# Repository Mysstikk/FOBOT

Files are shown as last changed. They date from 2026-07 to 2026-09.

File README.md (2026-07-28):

# FOBOT — Feeding Collaborative Robot

FOBOT es un prototipo de robot colaborativo de seis grados de libertad diseñado para asistir durante la alimentación de personas con movilidad reducida o diversidad funcional.

El sistema combina actuadores Dynamixel, ROS 2, MoveIt 2 y visión artificial para ejecutar una secuencia de recogida de comida y aproximar una cuchara a la boca del usuario mediante control visual.

Este repositorio contiene el código fuente desarrollado para el Trabajo de Fin de Grado:

> *Design and implementation of a collaborative robot for feeding with control through artificial vision*

Autor: Unai Mollá Caballero  
Tutor: Jaime Masiá Vañó  
Universitat Politècnica de València — Campus d'Alcoi  
Curso: 2025–2026

## Características principales

- Control de seis actuadores Dynamixel.
- Integración del hardware mediante `ros2_control`.
- Ejecución de trayectorias articulares previamente configuradas.
- Grabación de posiciones mediante guiado manual.
- Coordinación del comportamiento mediante una máquina de estados finitos.
- Detección facial mediante MediaPipe.
- Reconocimiento de la apertura de la boca y el cierre de los ojos.
- Estimación tridimensional de la posición de la boca.
- Aproximación mediante MoveIt Servo.
- Supervisión de singularidades y colisiones.
- Detección de posibles contactos mediante el esfuerzo de los motores.
- Interfaz física mediante pulsadores e indicadores LED.

## Arquitectura del repositorio

```text
FOBOT/
├── robot_pkg/                 # Control principal, FSM y movimientos
├── fobot_moveit_config/       # Configuración de MoveIt 2
├── fobot_vision/              # Detección facial y control visual
├── singularity_probe/         # Análisis del jacobiano
├── DynamixelSDK               # SDK de los motores Dynamixel
├── dynamixel_interfaces/      # Mensajes y servicios de Dynamixel
├── dynamixel_hardware_interface/
│                              # Integración con ros2_control
└── README.md
```

La estructura puede variar dependiendo de la versión publicada.

## Requisitos

El sistema se ha desarrollado utilizando:

- Ubuntu 22.04.
- ROS 2 Humble.
- Python 3.
- C++.
- MoveIt 2.
- `ros2_control`.
- Dynamixel SDK.
- OpenCV.
- MediaPipe.
- Cámara USB.
- Raspberry Pi 4.

También se necesitan los paquetes de ROS 2 correspondientes a MoveIt Servo, TF2, `usb_cam` y el controlador de trayectorias articulares.

## Instalación

Crear un espacio de trabajo de ROS 2:

```bash
mkdir -p ~/fobot_ws/src
cd ~/fobot_ws/src
```

Clonar el repositorio:

```bash
git clone <URL_DEL_REPOSITORIO>
```

Instalar las dependencias:

```bash
cd ~/fobot_ws
rosdep install --from-paths src --ignore-src -r -y
```

Compilar:

```bash
colcon build --symlink-install
source install/setup.bash
```

La instrucción `source install/setup.bash` debe ejecutarse en cada nueva terminal desde la que se utilice el robot.

## Configuración previa

Antes de iniciar el sistema se debe comprobar:

1. Que cada motor Dynamixel tenga un identificador diferente.
2. Que el puerto serie y la velocidad de comunicación sean correctos.
3. Que la cámara esté conectada y calibrada.
4. Que el plato y el robot estén situados en las posiciones utilizadas durante la configuración.
5. Que la cuchara esté limpia y correctamente fijada.
6. Que no haya obstáculos dentro del espacio de trabajo.

Los parámetros principales se encuentran en los archivos YAML de los paquetes correspondientes.

## Ejecución

Para iniciar el sistema completo:

```bash
ros2 launch robot_pkg FOBOT.launch.py
```

El fichero maestro inicia los controladores, la descripción del robot, la máquina de estados, el sistema de visión y MoveIt Servo.

Después del arranque se debe realizar el movimiento de *homing* antes de comenzar la secuencia de alimentación.

## Grabación de trayectorias

El movimiento automático utiliza una secuencia de posiciones articulares almacenada en un fichero CSV.

El programa de grabación permite:

1. Desactivar el par de los motores.
2. Mover manualmente el brazo.
3. Registrar las posiciones deseadas.
4. Volver a activar el par.
5. Probar la trayectoria antes de utilizarla con comida.

Las primeras pruebas deben realizarse sin situar al usuario dentro del alcance inmediato del robot.

## Funcionamiento general

La secuencia de alimentación es la siguiente:

1. El robot realiza el movimiento de *homing*.
2. El usuario abre la boca para iniciar el ciclo.
3. El robot ejecuta la trayectoria de recogida.
4. La cuchara se desplaza hasta una posición próxima al rostro.
5. El usuario vuelve a abrir la boca para confirmar la entrega.
6. El sistema de visión estima la posición de la boca.
7. MoveIt Servo realiza la aproximación final.
8. El robot regresa para recoger una nueva porción.
9. El usuario puede finalizar el proceso cerrando ambos ojos.

## Limitaciones

El prototipo presenta actualmente las siguientes limitaciones:

- No detecta automáticamente la comida presente en el plato.
- La recogida utiliza trayectorias previamente grabadas.
- El plato debe permanecer en una posición aproximadamente fija.
- La profundidad se estima mediante una cámara RGB monocular.
- El comportamiento puede verse afectado por la iluminación y las oclusiones.
- No se ha realizado una validación clínica ni una certificación de seguridad.
- El sistema debe utilizarse en un entorno controlado y con supervisión.

## Seguridad

Este software pertenece a un prototipo académico y no constituye un producto médico o asistencial certificado.

Antes de utilizarlo:

- Mantener despejado el espacio de trabajo.
- No introducir las manos mientras los motores estén activos.
- Comprobar la temperatura y consistencia de la comida.
- Verificar la fijación de la cuchara.
- No rearmar el sistema sin identificar la causa de la parada.
- Utilizar el interruptor de alimentación si el robot presenta un comportamiento inesperado.

El uso del código y del prototipo se realiza bajo la responsabilidad de la persona que lo instala y opera.

Unai Mollá Caballero

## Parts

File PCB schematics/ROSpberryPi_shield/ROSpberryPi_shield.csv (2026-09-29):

Reference | Value | Datasheet | Footprint | Qty
C1 | 100uf |  | Capacitor_SMD:CP_Elec_8x10.5 | 1
C2 | 100nf |  | Capacitor_Tantalum_SMD:CP_EIA-1608-10_AVX-L | 1
C3 | 100nf |  | Capacitor_Tantalum_SMD:CP_EIA-1608-10_AVX-L | 1
C4 | 100nf |  | Capacitor_Tantalum_SMD:CP_EIA-1608-10_AVX-L | 1
C5 | 100nf |  | Capacitor_Tantalum_SMD:CP_EIA-1608-10_AVX-L | 1
C6 | 100nf |  | Capacitor_Tantalum_SMD:CP_EIA-1608-10_AVX-L | 1
C7 | 100nf |  | Capacitor_Tantalum_SMD:CP_EIA-1608-10_AVX-L | 1
C8 | 100nf |  | Capacitor_Tantalum_SMD:CP_EIA-1608-10_AVX-L | 1
C9 | 100nf |  | Capacitor_Tantalum_SMD:CP_EIA-1608-10_AVX-L | 1
C10 | 100nf |  | Capacitor_Tantalum_SMD:CP_EIA-1608-10_AVX-L | 1
C11 | 100nf |  | Capacitor_Tantalum_SMD:CP_EIA-1608-10_AVX-L | 1
C12 | 100nf |  | Capacitor_Tantalum_SMD:CP_EIA-1608-10_AVX-L | 1
D1 | RED |  | LED_SMD:LED_0201_0603Metric | 1
D2 | SS34 | http://www.vishay.com/docs/88526/1n5820.pdf | Diode_THT:D_DO-201AD_P15.24mm_Horizontal | 1
D3 | GREEN |  | LED_SMD:LED_0603_1608Metric | 1
D4 | PESD5V0L1BA | https://datasheet.datasheetarchive.com/originals/distributors/Datasheets-26/DSA-502684.pdf | My_Lib:SOD2512X110N | 1
IC3 | NC7WZ241K8X | https://www.onsemi.com/pub/Collateral/NC7WZ241-D.PDF | My_Lib:SOP50P310X90-8N | 1
J1 | Conn_01x03_Pin |  | Connector_Molex:Molex_KK-254_AE-6410-03A_1x03_P2.54mm_Vertical | 1
J8 | Conn_01x03_Pin |  | Connector_Molex:Molex_KK-254_AE-6410-03A_1x03_P2.54mm_Vertical | 1
J9 | Conn_01x03_Pin |  | Connector_Molex:Molex_KK-254_AE-6410-03A_1x03_P2.54mm_Vertical | 1
J11 | Conn_01x03_Pin |  | Connector_Molex:Molex_KK-254_AE-6410-03A_1x03_P2.54mm_Vertical | 1
J12 | Conn_01x03_Pin |  | Connector_Molex:Molex_KK-254_AE-6410-03A_1x03_P2.54mm_Vertical | 1
J13 | Conn_01x03_Pin |  | Connector_Molex:Molex_KK-254_AE-6410-03A_1x03_P2.54mm_Vertical | 1
J14 | Conn_01x03_Pin |  | Connector_Molex:Molex_KK-254_AE-6410-03A_1x03_P2.54mm_Vertical | 1
J15 | Conn_01x03_Pin |  | Connector_Molex:Molex_KK-254_AE-6410-03A_1x03_P2.54mm_Vertical | 1
J16 | Conn_01x04_Pin |  | Connector_Molex:Molex_KK-254_AE-6410-04A_1x04_P2.54mm_Vertical | 1
R1 | 390 |  | Resistor_SMD:R_0201_0603Metric | 1
R2 | 220 |  | Resistor_SMD:R_0201_0603Metric | 1
R3 | 150 |  | Resistor_SMD:R_0201_0603Metric | 1
R4 | 150 |  | Resistor_SMD:R_0201_0603Metric | 1
R5 | 100 |  | Resistor_SMD:R_0201_0603Metric | 1
R6 | 100 |  | Resistor_SMD:R_0201_0603Metric | 1
R7 | 10k |  | Resistor_SMD:R_0201_0603Metric | 1
R8 | 2.2k |  | Resistor_SMD:R_0201_0603Metric | 1
R9 | 2.2k |  | Resistor_SMD:R_0201_0603Metric | 1
U2 | BNO085 |  | My_Lib:IC_BNO085 | 1
U3 | TXB0104D | http://www.ti.com/lit/ds/symlink/txb0104.pdf | Package_SO:SOIC-14_3.9x8.7mm_P1.27mm | 1
U4 | MCP3008 | http://ww1.microchip.com/downloads/en/DeviceDoc/21295d.pdf | Package_DIP:DIP-16_W7.62mm | 1

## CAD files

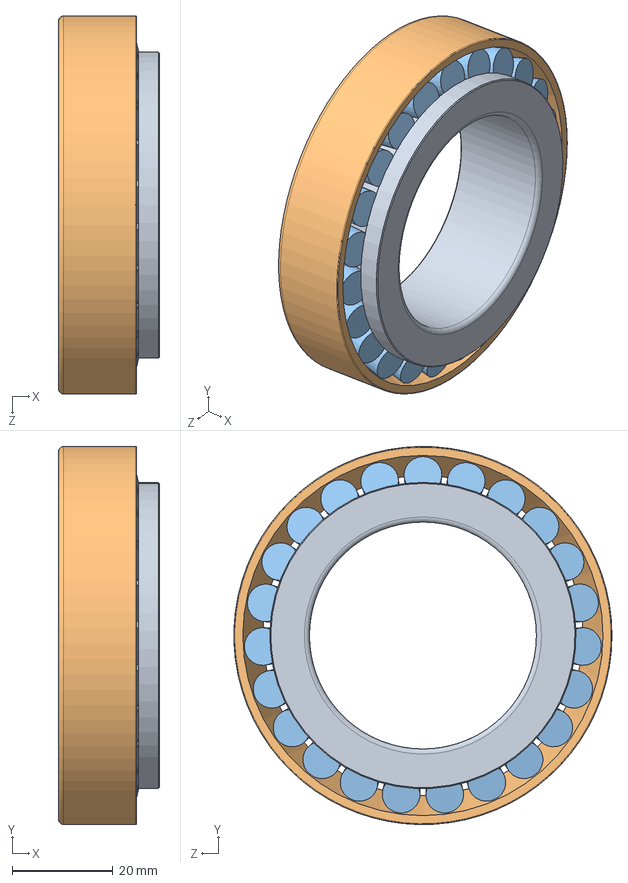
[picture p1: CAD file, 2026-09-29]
model/skf_bearing_32009_x_2.SLDASM
20.0 x 75.0 x 75.0 mm
skf_bearing_32009_x_2_01
skf_bearing_32009_x_2_02
skf_bearing_32009_x_2_03

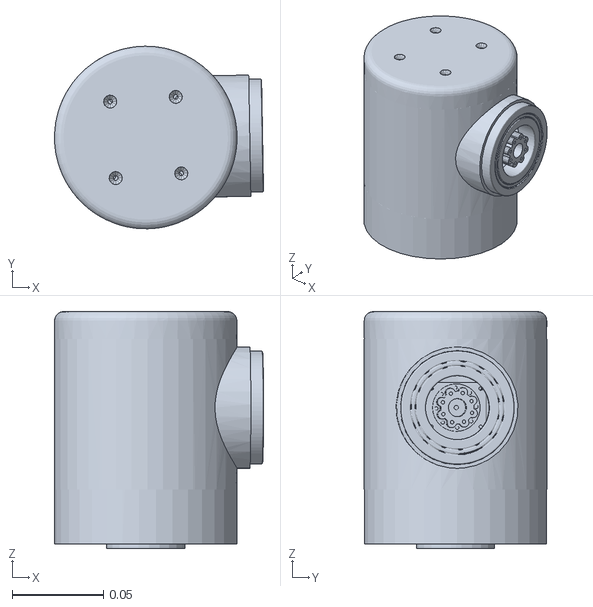
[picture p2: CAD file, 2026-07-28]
robot_pkg/urdf/meshes/link_hombro.STL
0.115 x 0.1 x 0.13

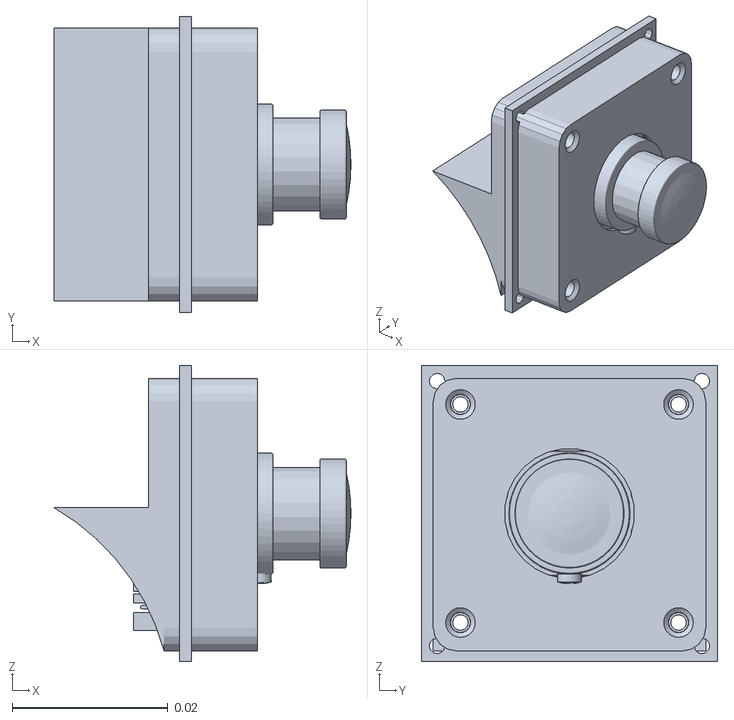
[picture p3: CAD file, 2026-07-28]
robot_pkg/urdf/meshes/link_camara.STL
0.0381 x 0.038 x 0.038

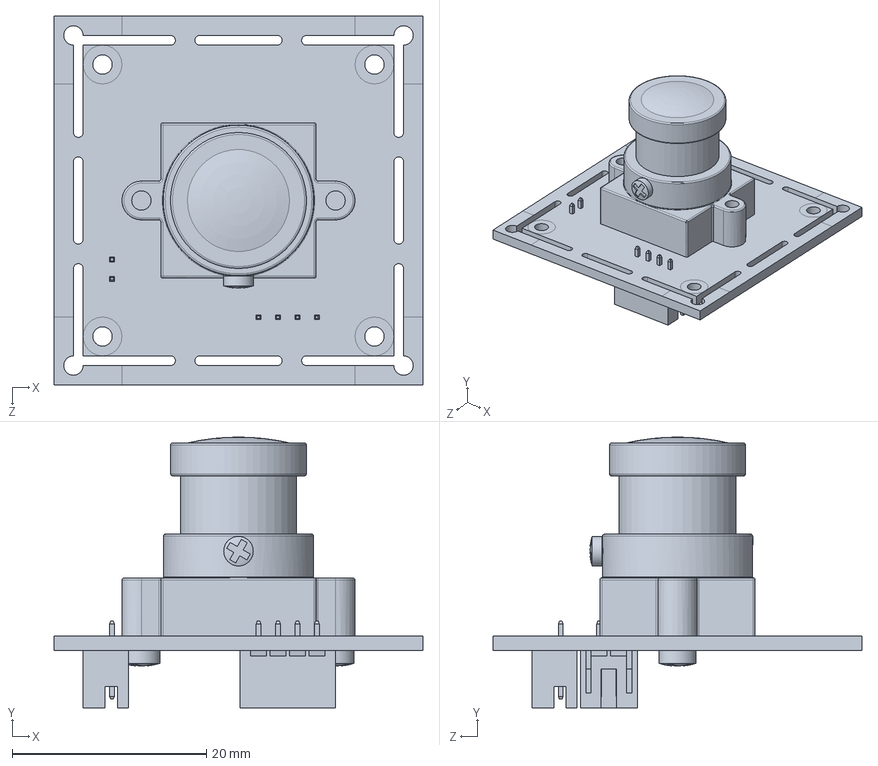
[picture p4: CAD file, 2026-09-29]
model/USB Cam model ELP-USBFHD01M-L21.SLDPRT
38.0 x 27.9 x 38.0 mm

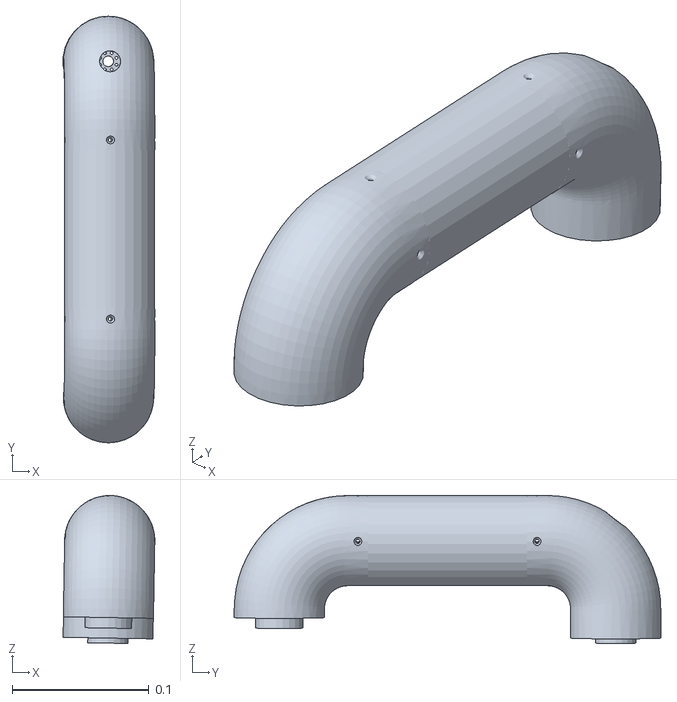
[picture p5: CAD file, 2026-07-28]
robot_pkg/urdf/meshes/link_hombro_codo.STL
0.0671 x 0.312 x 0.108

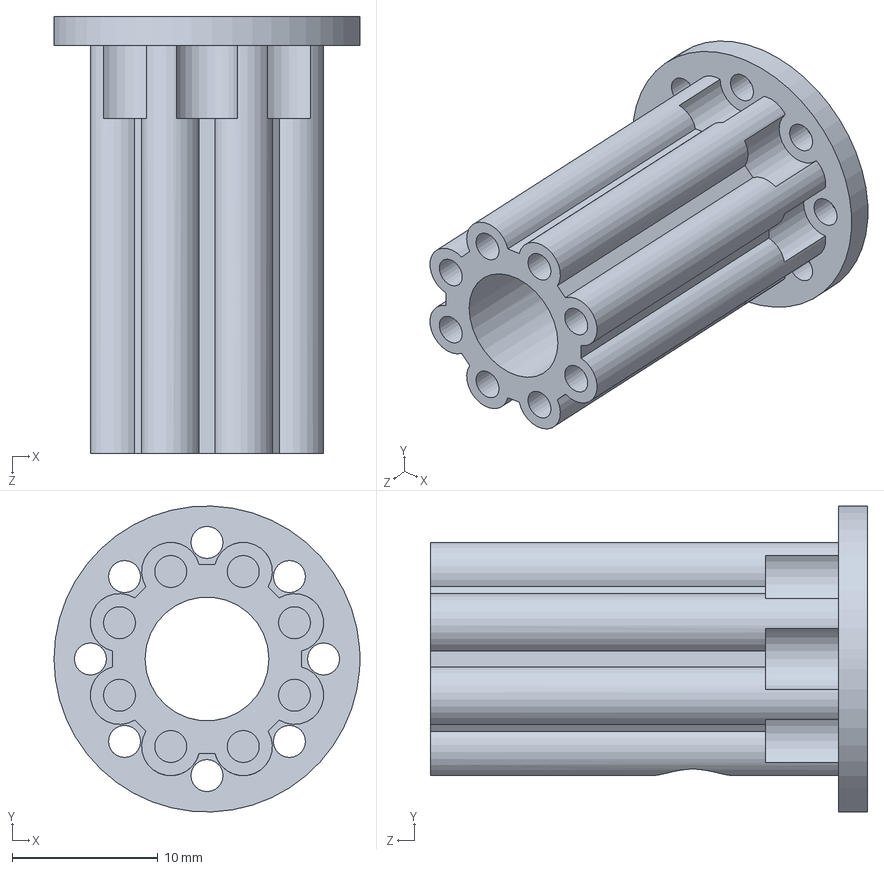
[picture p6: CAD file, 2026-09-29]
model/Soporte_Eslabon_3.SLDPRT
21.0 x 21.0 x 30.0 mm

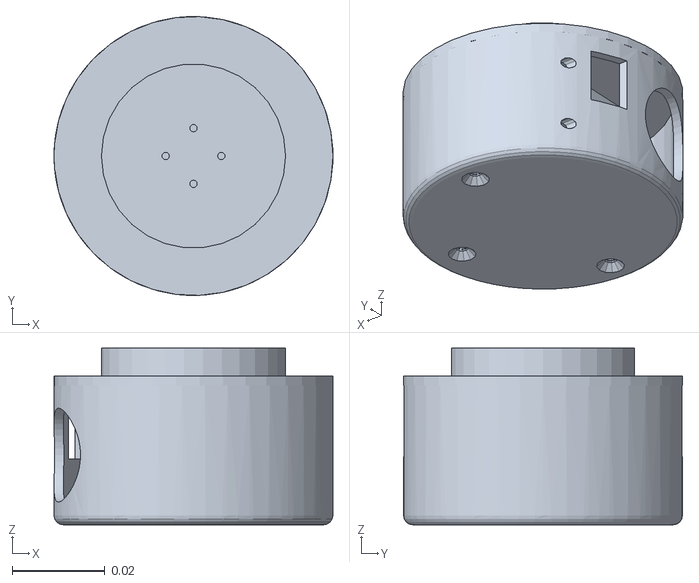
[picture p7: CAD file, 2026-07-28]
robot_pkg/urdf/meshes/link_muneca.STL
0.06 x 0.06 x 0.038

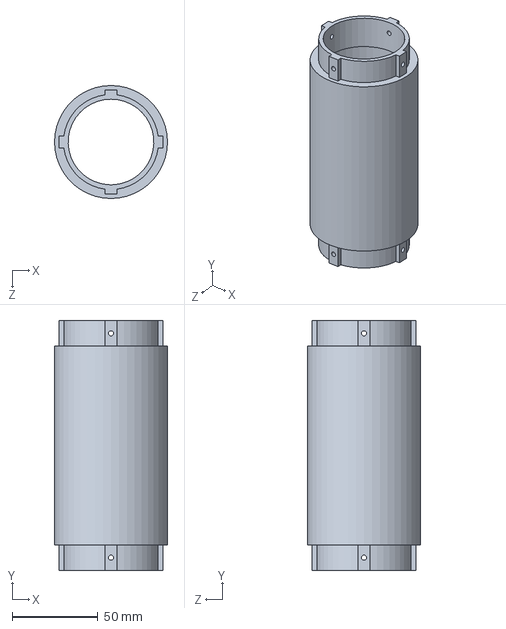
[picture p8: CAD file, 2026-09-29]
model/Eslabon_3.SLDPRT
66.0 x 146.0 x 66.0 mm

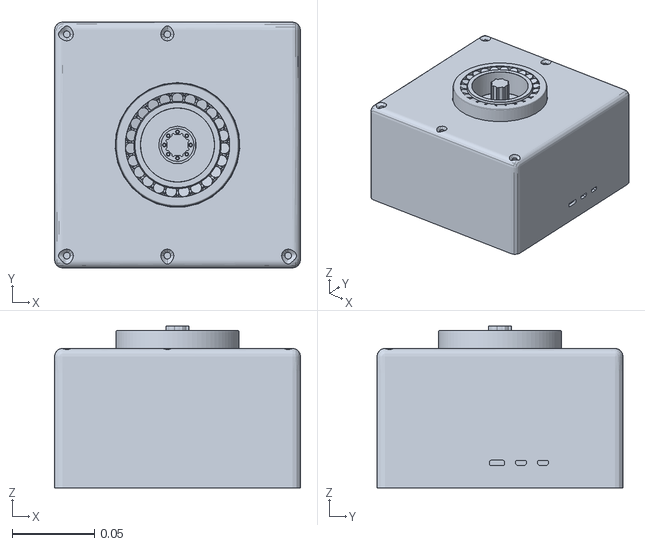
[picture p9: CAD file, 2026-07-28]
robot_pkg/urdf/meshes/base_link.STL
0.15 x 0.15 x 0.0985

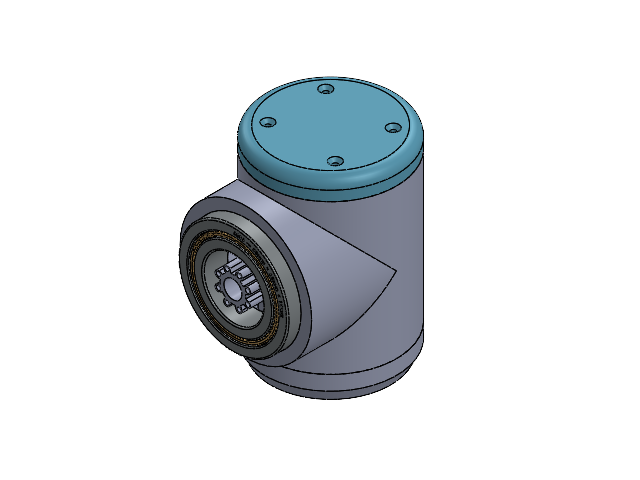
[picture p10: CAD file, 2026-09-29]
model/Eslabon_Codo.SLDASM
Eslabon_4
Cubierta_Eslabon_3
Tapa_Eslabon_3
DUMMY_DC12.stp
WBH_M2_5X12.stp x 8
DC12_A01_SPACER_RING_1.stp x 8
DC12_A01_CVR_CABLE_5.stp
p BEARING, SINGLE-ROW RADIAL, OPEN, METRIC 6000 SERIES — 6006 — 30mm × 55mm × 13mm
Pieza1^Eslabon_Codo

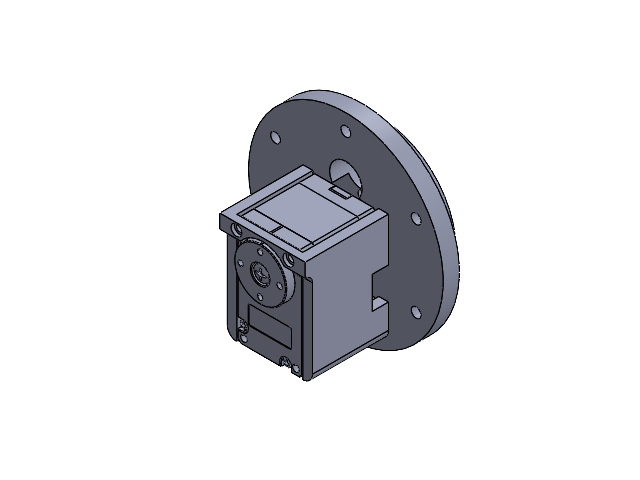
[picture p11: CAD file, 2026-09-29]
model/Eslabon_Muneca_Herramienta.SLDASM
Eslabon_5
DC15_A01_CASE_M_DUMMY.stp
DC15_A01_CASE_F_DUMMY.stp
DC15_A01_CASE_B_DUMMY.stp
DC15_A01_HORN_DUMMY.stp
DC15_A01_LED_CAP2_DUMMY.stp
PHS_1_7X20_5_DC10.stp x 4
BTS2_M2_6X8.stp
B3B-EH.stp x 2
Pieza1^Eslabon_Muneca_Herramienta

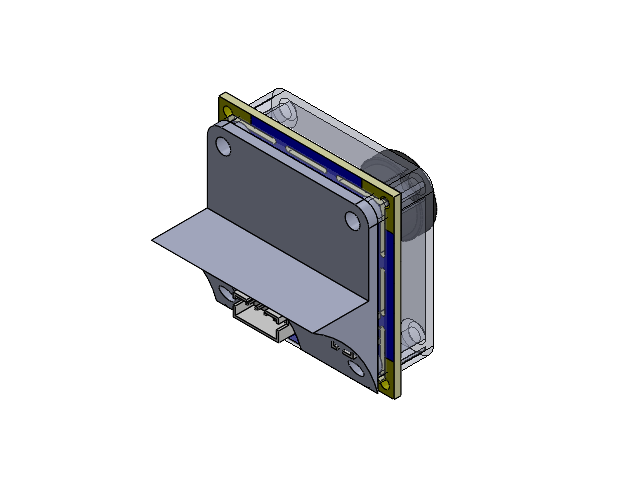
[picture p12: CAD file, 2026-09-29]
model/Ensamb_Camara.SLDASM
Soporte_Camara
Tapa_Camara
USB Cam model ELP-USBFHD01M-L21

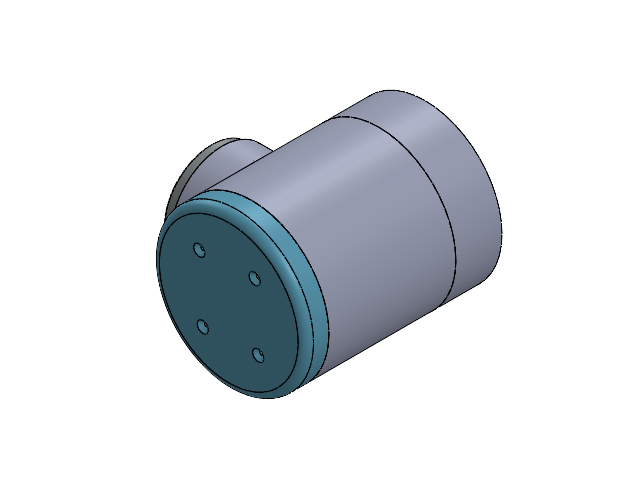
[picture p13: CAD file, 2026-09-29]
model/Eslabon_Hombro.SLDASM
Eslabon_1
XM540.step
Cubierta_Eslabon_1
p BEARING, SINGLE-ROW RADIAL, OPEN, METRIC 6000 SERIES — 6007 — 35mm × 62mm × 14mm
Soporte_Eslabon_2
Tapa_Eslabon_1

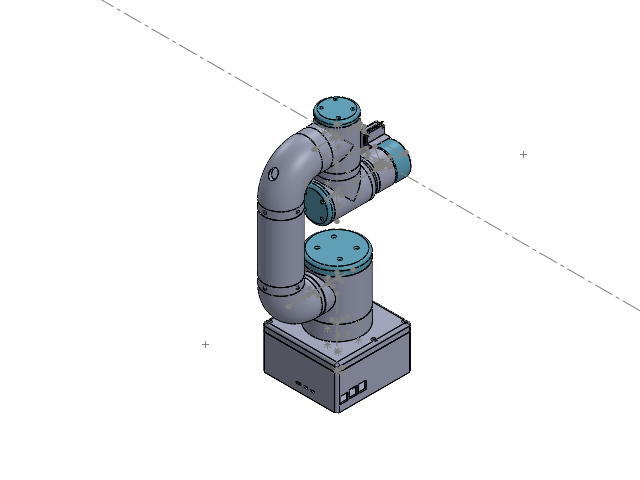
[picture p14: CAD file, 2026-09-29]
model/FOBOT.SLDASM
BaseRobot
Tapa_Base_Robot
DUMMY_DC12.stp x 3
WBH_M2_5X12.stp x 24
DC12_A01_SPACER_RING_1.stp x 24
DC12_A01_CVR_CABLE_5.stp x 3
Soporte_Eslabon
skf_bearing_32009_x_2_01
skf_bearing_32009_x_2_02
skf_bearing_32009_x_2_03
Eslabon_1
XM540.step
Cubierta_Eslabon_1
p BEARING, SINGLE-ROW RADIAL, OPEN, METRIC 6000 SERIES — 6007 — 35mm × 62mm × 14mm
Soporte_Eslabon_2
Tapa_Eslabon_1
Eslabon_2
Cubierta_Eslabon_2
p BEARING, SINGLE-ROW RADIAL, OPEN, METRIC 6000 SERIES — 6006 — 30mm × 55mm × 13mm x 2
Tapa_Eslabon_2
Soporte_Eslabon_3
Eslabon_3_2
Eslabon_3
Eslabon_3_2_sup
Eslabon_4
Cubierta_Eslabon_3
Tapa_Eslabon_3
Pieza1^Eslabon_Codo
Eslabon_5
Cubierta_Eslabon_5
61808-2rs1_01
61808-2rs1_02
61808-2rs1_03
61808-2rs1_04
61808-2rs1_05
DC15_A01_CASE_M_DUMMY.stp x 2
DC15_A01_CASE_F_DUMMY.stp x 2
DC15_A01_CASE_B_DUMMY.stp x 2
DC15_A01_HORN_DUMMY.stp x 2
DC15_A01_LED_CAP2_DUMMY.stp x 2
PHS_1_7X20_5_DC10.stp x 8
BTS2_M2_6X8.stp x 2
B3B-EH.stp x 4
Pieza1^Eslabon_Muneca_Herramienta
Eslabon_6
Soporte_Herramienta
Herramienta_1
Tapa_Herramienta
Soporte_Camara
Tapa_Camara
USB Cam model ELP-USBFHD01M-L21

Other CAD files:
model/Base_Robot.SLDASM
model/Eslabon_Hombro_Codo.SLDASM
model/Eslabon_Herramienta.SLDASM
robot_pkg/urdf/meshes/link_tcp.STL
model/61808-2rs1.SLDASM
model/61808-2rs1_01.SLDPRT
model/61808-2rs1_02.SLDPRT
model/61808-2rs1_03.SLDPRT
model/61808-2rs1_04.SLDPRT
model/61808-2rs1_05.SLDPRT
model/BaseRobot.SLDPRT
model/Cubierta_Eslabon_1.SLDPRT
model/Cubierta_Eslabon_2.SLDPRT
model/Cubierta_Eslabon_3.SLDPRT
model/Cubierta_Eslabon_5.SLDPRT
model/Eslabon_1.SLDPRT
model/Eslabon_2.SLDPRT
model/Eslabon_3_2.SLDPRT
model/Eslabon_3_2_sup.SLDPRT
model/Eslabon_4.SLDPRT
model/Eslabon_5.SLDPRT
model/Eslabon_6.SLDPRT
model/Herramienta_1.SLDPRT
model/Pieza1^Eslabon_Codo.SLDPRT
model/Soporte_Camara.SLDPRT
model/Soporte_Eslabon.SLDPRT
model/Soporte_Eslabon_2.SLDPRT
model/Soporte_Herramienta.SLDPRT
model/Tapa_Base_Robot.SLDPRT
model/Tapa_Camara.SLDPRT
model/Tapa_Eslabon_1.SLDPRT
model/Tapa_Eslabon_2.SLDPRT
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

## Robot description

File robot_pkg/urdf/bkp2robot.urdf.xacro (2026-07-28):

<?xml version="1.0" encoding="utf-8"?>
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
<robot name="FOBOT" xmlns:xacro="http://www.ros.org/wiki/xacro">
  <link name="world_link" />

  <joint name="world_joint" type="fixed">
    <parent link="world_link" />
    <child link="base_link" />
    <origin xyz="0 0 0" rpy="0 0 0" />
  </joint>
  <link name="base_link">
    <inertial>
      <origin xyz="-0.000324527792386832 0.000535590007123509 0.0536555243566054" rpy="0 0 0" />
      <mass value="0.640667020480894" />
      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
    </inertial>
    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
  </link>
  <link name="link_hombro">
    <inertial>
      <origin xyz="0.0177586720760899 0.000311723505450981 0.0594351103623852" rpy="0 0 0" />
      <mass value="0.654879795952153" />
      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
    </inertial>
    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
  </link>
  <joint name="joint_hombro" type="revolute">
    <origin xyz="0 0 0.0831" rpy="0 0 0" />
    <parent link="base_link" />
    <child link="link_hombro" />
    <axis xyz="0 0 1" />
    <limit lower="-1.57" upper="1.57" effort="10" velocity="3.14" />
  </joint>
  <link name="link_hombro_codo">
    <inertial>
      <origin xyz="0.00174671434810424 0.127639245502884 0.0995470053851245" rpy="0 0 0" />
      <mass value="0.36538432537355" />
      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
    </inertial>
    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
  </link>
  <joint name="joint_hombro_codo" type="revolute">
    <origin xyz="0 0 0.07715" rpy="1.5708 0 1.5708" />
    <parent link="link_hombro" />
    <child link="link_hombro_codo" />
    <axis xyz="0 0 1" />
    <limit lower="-1.57" upper="1.57" effort="10" velocity="3.14" />
  </joint>
  <link name="link_codo">
    <inertial>
      <origin xyz="-0.00516428980556016 -0.000391330935633924 0.0223035602244459" rpy="0 0 0" />
      <mass value="0.314093246133126" />
      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
    </inertial>
    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
  </link>
  <joint name="joint_codo" type="revolute">
    <origin xyz="0 0.246 0" rpy="0 0 1.5708" />
    <parent link="link_hombro_codo" />
    <child link="link_codo" />
    <axis xyz="0 0 -1" />
    <limit lower="-1.57" upper="1.57" effort="10" velocity="3.14" />
  </joint>
  <link name="link_codo_muneca">
    <inertial>
      <origin xyz="-1.39307723388693E-07 0.0135191619848798 0.0172025714731864" rpy="0 0 0" />
      <mass value="0.392047475790556" />
      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
    </inertial>
    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
  </link>
  <joint name="joint_codo_muneca" type="revolute">
    <origin xyz="-0.09705 0 0" rpy="-1.5708 0 -1.5708" />
    <parent link="link_codo" />
    <child link="link_codo_muneca" />
    <axis xyz="0 0 -1" />
    <limit lower="-1.57" upper="1.57" effort="10" velocity="3.14" />
  </joint>
  <link name="link_muneca">
    <inertial>
      <origin xyz="0.0011814 -0.00012981 -0.014057" rpy="0 0 0" />
      <mass value="0.051202" />
      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
    </inertial>
    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
  </link>
  <joint name="joint_muneca" type="revolute">
    <origin xyz="0 0.086566 0" rpy="1.5708 0 0" />
    <parent link="link_codo_muneca" />
    <child link="link_muneca" />
    <axis xyz="0 0 -1" />
    <limit lower="-1.57" upper="1.57" effort="10" velocity="3.14" />
  </joint>
  <link name="link_herramienta">
    <inertial>
      <origin xyz="-0.0066648 -0.00010158 -0.053829" rpy="0 0 0" />
      <mass value="0.010917" />
      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
    </inertial>
    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
  </link>
  <joint name="joint_herramienta" type="revolute">
    <origin xyz="0 -0.0075 -0.018384" rpy="1.5708 0 1.5708" />
    <parent link="link_muneca" />
    <child link="link_herramienta" />
    <axis xyz="0 0 -1" />
    <limit lower="-1.57" upper="1.57" effort="10" velocity="3.14" />
  </joint>
  <link name="link_tcp">
    
  </link>
  <joint name="joint_tcp_fixed" type="fixed">
    <origin xyz="0 0 -0.10829" rpy="0 1.5708 0" />
    <parent link="link_herramienta" />
    <child link="link_tcp" />
    <axis xyz="0 0 0" />
  </joint>
  <link name="link_camara">
    <inertial>
      <origin xyz="-0.019021 -9.3975E-05 -0.00037502" rpy="0 0 0" />
      <mass value="0.012812" />
      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
    </inertial>
    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
  </link>
  <joint name="joint_camara_fixed" type="fixed">
    <origin xyz="-0.052668 0.025492 -0.018384" rpy="1.5708 0 -3.1416" />
    <parent link="link_muneca" />
    <child link="link_camara" />
    <axis xyz="0 0 0" />
  </joint>
  
  <ros2_control name="DynamixelSystem" type="system">
    <hardware>
      <plugin>dynamixel_hardware_interface/DynamixelHardware</plugin>
      
      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
      <param name="port_name">/dev/ttyUSB0</param>
      
      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
      <param name="baud_rate">1000000</param>
      <param name="protocol_version">2.0</param>
      <param name="use_dummy">false</param> 
      <param name="error_timeout_sec">1.0</param>
      <param name="number_of_joints">6</param> 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
      <param name="number_of_transmissions">6</param> 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
      <param name="disable_torque_at_init">true</param> 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
      <param name="error_timeout_sec">0.2</param>
      <param name="dynamixel_model_folder">/param/dxl_model</param> 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
      <param name="transmission_to_joint_matrix">
      1,0,0,0,0,0,
      0,1,0,0,0,0,
      0,0,1,0,0,0,
      0,0,0,1,0,0,
      0,0,0,0,1,0,
      0,0,0,0,0,1
      </param>
      <param name="joint_to_transmission_matrix">
      1,0,0,0,0,0,
      0,1,0,0,0,0,
      0,0,1,0,0,0,
      0,0,0,1,0,0,
      0,0,0,0,1,0,
      0,0,0,0,0,1
      </param>
      
      <param name="ros_update_freq">200</param>
      <param name="dynamixel_state_pub_msg_name">dynamixel_hardware_interface/dxl_state</param>
      <param name="get_dynamixel_data_srv_name">dynamixel_hardware_interface/get_dxl_data</param>
      <param name="set_dynamixel_data_srv_name">dynamixel_hardware_interface/set_dxl_data</param>
      <param name="reboot_dxl_srv_name">dynamixel_hardware_interface/reboot_dxl</param>
      <param name="set_dxl_torque_srv_name">dynamixel_hardware_interface/set_dxl_torque</param>
    </hardware>

    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
    <joint name="joint_hombro">
      <command_interface name="position"/>
      <state_interface name="position"/>
      <state_interface name="velocity"/>
      <state_interface name="effort"/>
    </joint>
    
    <joint name="joint_hombro_codo">
      <command_interface name="position"/>
      <state_interface name="position"/>
      <state_interface name="velocity"/>
      <state_interface name="effort"/>
    </joint>
    
    <joint name="joint_codo">
      <command_interface name="position"/>
      <state_interface name="position"/>
      <state_interface name="velocity"/>
      <state_interface name="effort"/>
    </joint>
    
    <joint name="joint_codo_muneca">
      <command_interface name="position"/>
      <state_interface name="position"/>
      <state_interface name="velocity"/>
      <state_interface name="effort"/>
    </joint>
    
    <joint name="joint_muneca">
      <command_interface name="position"/>
      <state_interface name="position"/>
      <state_interface name="velocity"/>
      <state_interface name="effort"/>
    </joint>
    
    <joint name="joint_herramienta">
      <command_interface name="position"/>
      <state_interface name="position"/>
      <state_interface name="velocity"/>
      <state_interface name="effort"/>
    </joint>
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

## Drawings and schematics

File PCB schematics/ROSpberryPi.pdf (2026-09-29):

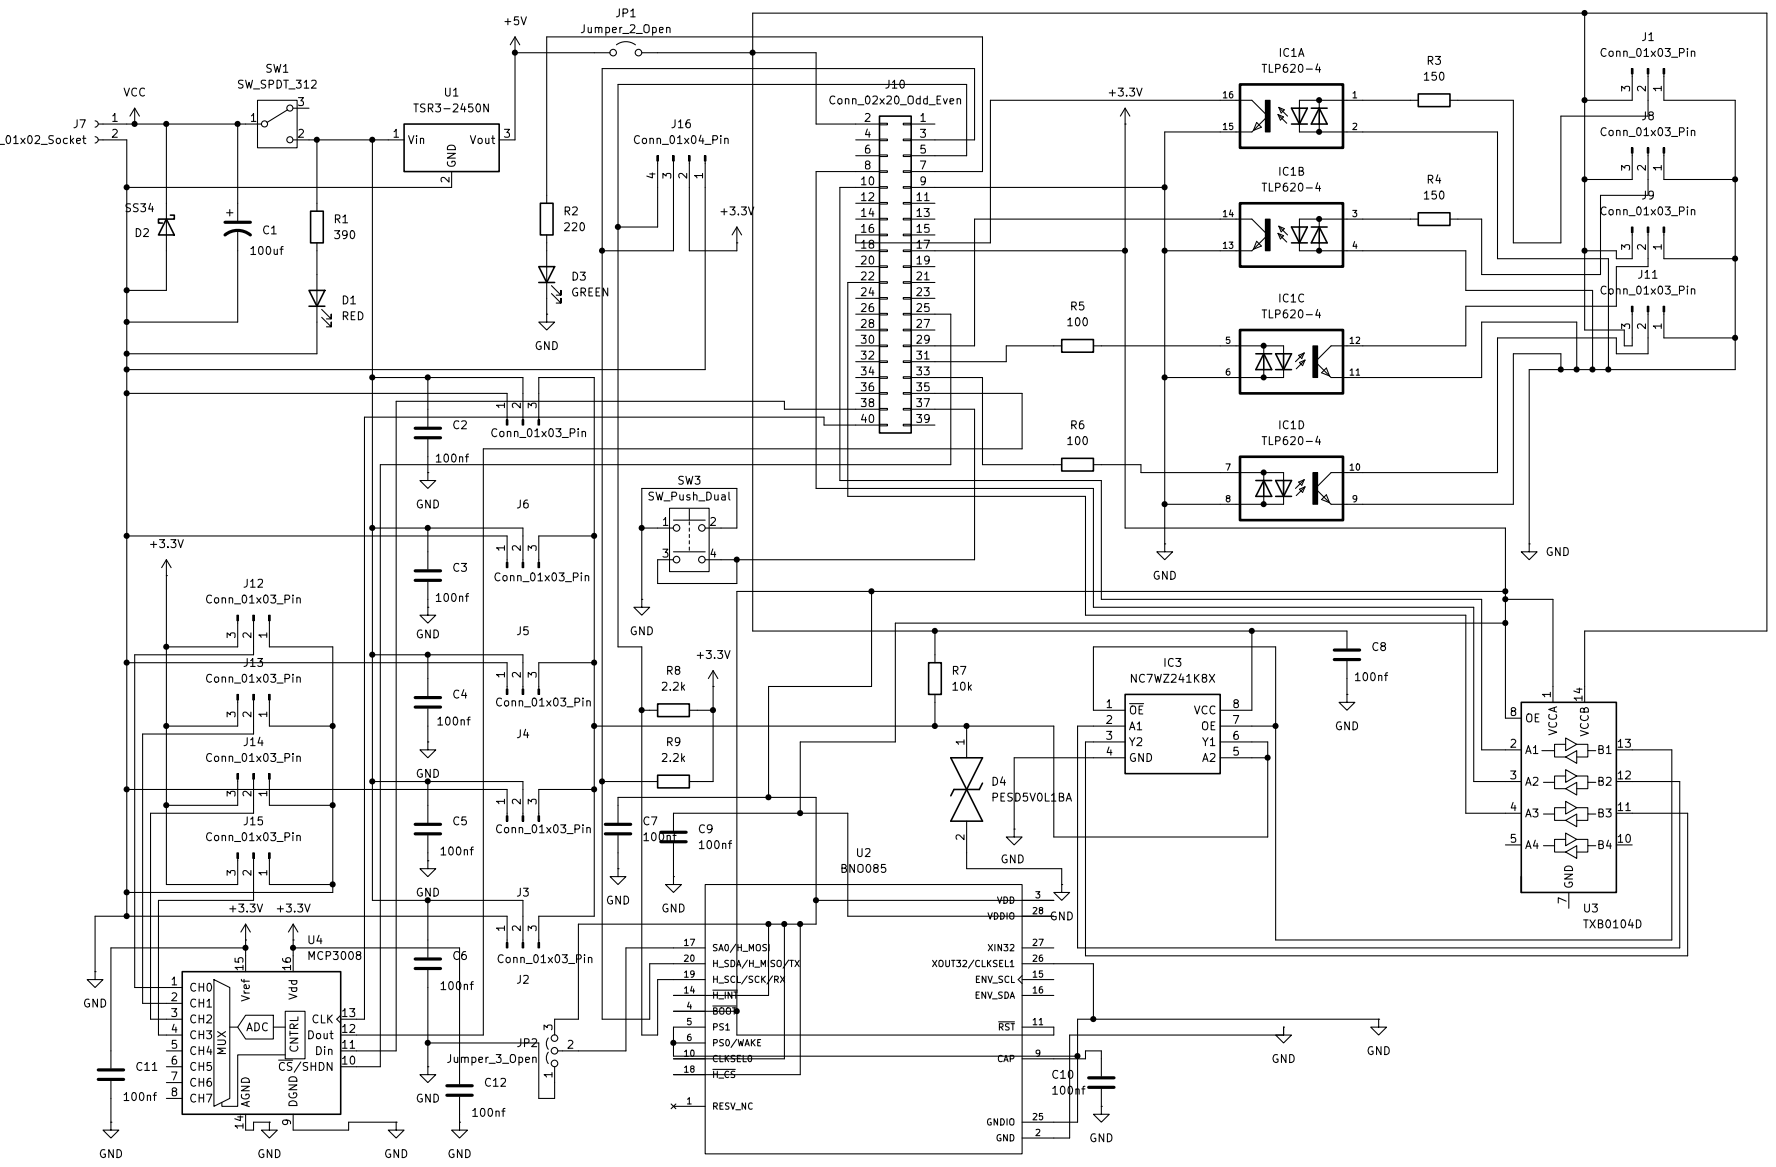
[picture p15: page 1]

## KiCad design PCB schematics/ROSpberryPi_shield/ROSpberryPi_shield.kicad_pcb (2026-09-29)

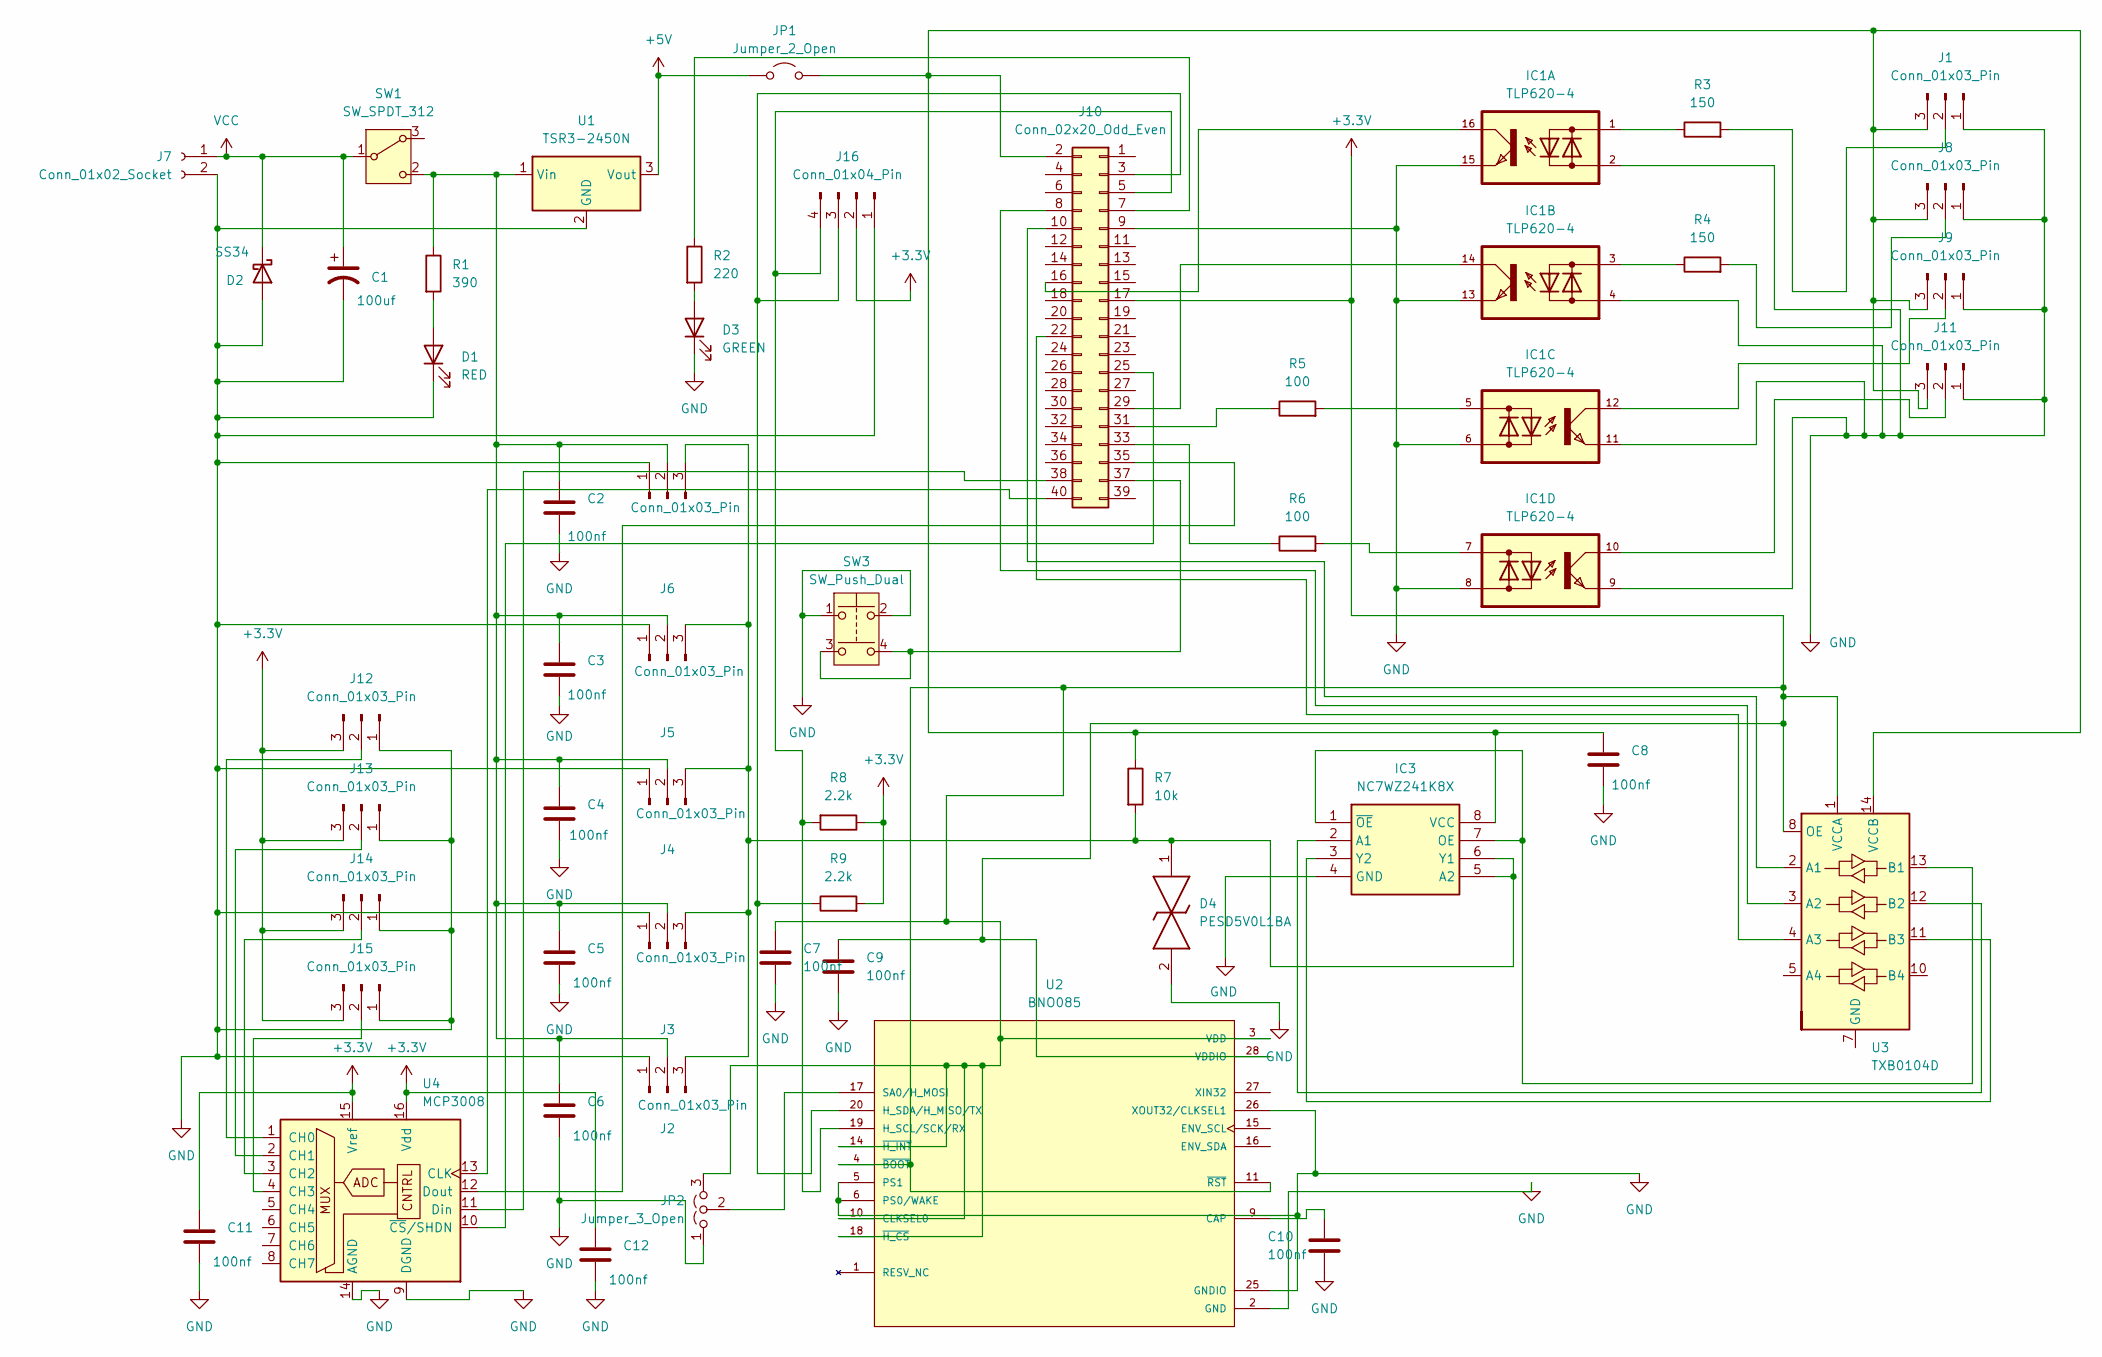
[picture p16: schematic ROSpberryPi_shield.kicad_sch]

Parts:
C1: 100uf; CP_Elec_8x10.5
C2, C3, C4, C5, C6, C7, C8, C9, C10, C11, C12: 100nf; CP_EIA-1608-10_AVX-L
D1: RED; LED_0603_1608Metric
D2: SS34; D_DO-201AD_P15.24mm_Horizontal
D3: GREEN; LED_0603_1608Metric
D4: PESD5V0L1BA; SOD2512X110N; Manufacturer_Part_Number PESD5V0L1BA; Mouser Part Number N/A
IC1: TLP620-4; DIP762W60P254L1982H485Q16N
IC3: NC7WZ241K8X; SOP50P310X90-8N; Manufacturer_Part_Number NC7WZ241K8X; Mouser Part Number 512-NC7WZ241K8X
J1, J8, J9, J11, J12, J13, J14, J15: Conn_01x03_Pin; Molex_KK-254_AE-6410-03A_1x03_P2.54mm_Vertical
J2, J3, J4, J5, J6: Conn_01x03_Pin; JST_EH_B3B-EH-A_1x03_P2.50mm_Vertical
J7: Conn_01x02_Socket; TerminalBlock_4Ucon_1x02_P3.50mm_Vertical
J10: Conn_02x20_Odd_Even; PinSocket_2x20_P2.54mm_Vertical
J16: Conn_01x04_Pin; Molex_KK-254_AE-6410-04A_1x04_P2.54mm_Vertical
JP1: Jumper_2_Open; PinHeader_1x02_P2.54mm_Vertical
JP2: Jumper_3_Open; PinHeader_1x03_P2.54mm_Vertical
R1: 390; R_0603_1608Metric
R2: 220; R_0603_1608Metric
R3, R4: 150; R_0603_1608Metric
R5, R6: 100; R_0603_1608Metric
R7: 10k; R_0603_1608Metric
R8, R9: 2.2k; R_0603_1608Metric
SW1: SW_SPDT_312; 500SSP1S1M2QEA
SW3: SW_Push_Dual; DTS62NV
U1: TSR3-2450N; Converter_DCDC_TRACO_TSR2-24xxN_TSR2-24xxxN_THT
U2: BNO085; IC_BNO085; PARTREV v1.17
U3: TXB0104D; SOIC-14_3.9x8.7mm_P1.27mm
U4: MCP3008; DIP-16_W7.62mm

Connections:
+3.3V: C7.1, C9.1, C11.1, C12.1, J10.17, J12.3, J13.3, J14.3, J15.3, J16.2, JP2.3 (B), R8.1, R9.2, U2.3 (VDD), U2.4 (~BOOT), U2.10 (CLKSEL0), U2.11 (~RST), U2.14 (~H_INT), U2.18 (~H_CS), U2.28 (VDDIO), U3.1 (VCCA), U3.8 (OE), U4.15 (Vref), U4.16 (Vdd)
+5V: JP1.1 (A), U1.3 (Vout)
GND: C1.2, C2.2, C3.2, C4.2, C5.2, C6.2, C7.2, C8.2, C9.2, C10.2, C11.2, C12.2, D1.1 (K), D2.2 (A), D3.1 (K), D4.2, IC1.2, IC1.4, IC1.6, IC1.8, IC1.9, IC1.11, IC1.13, IC1.15, IC3.4 (GND), J1.1, J2.1, J3.1, J4.1, J5.1, J6.1, J7.2, J8.1, J9.1, J10.9, J11.1, J12.1, J13.1, J14.1, J15.1, J16.1, JP2.1 (A), SW3.1, SW3.2, U1.2 (GND), U2.2 (GND), U2.5 (PS1), U2.6 (PS0/WAKE), U2.25 (GNDIO), U2.26 (XOUT32/CLKSEL1), U4.9 (DGND), U4.14 (AGND)
unnamed: D1.2 (A), R1.2
unnamed: D3.2 (A), R2.2
unnamed: IC1.1, R3.1
unnamed: IC1.3, R4.1
unnamed: IC1.5, R5.2
unnamed: IC1.7, R6.2
unnamed: IC3.2 (A1), U3.12 (B2)
unnamed: D4.1, IC3.5 (A2), IC3.6 (Y1), J2.3, J3.3, J4.3, J5.3, J6.3, R7.2
unnamed: IC3.1 (~OE), IC3.7 (OE), U3.13 (B1)
unnamed: C8.1, IC3.8 (VCC), J1.3, J8.3, J9.3, J10.2, J11.3, JP1.2 (B), R7.1, U3.14 (VCCB)
unnamed: IC3.3 (Y2), U3.11 (B3)
unnamed: J1.2, R3.2
unnamed: C2.1, C3.1, C4.1, C5.1, C6.1, J2.2, J3.2, J4.2, J5.2, J6.2, R1.1, SW1.2 (C), U1.1 (Vin)
unnamed: J8.2, R4.2
unnamed: IC1.12, J9.2
unnamed: J10.3, J16.3, R9.1, U2.20 (H_SDA/H_MISO/TX)
unnamed: J10.5, J16.4, R8.2, U2.19 (H_SCL/SCK/RX)
unnamed: J10.7, R2.1
unnamed: J10.8, U3.3 (A2)
unnamed: J10.10, U3.2 (A1)
unnamed: IC1.16, J10.16
unnamed: J10.22, U3.4 (A3)
unnamed: J10.25, U4.10 (~CS/SHDN)
unnamed: IC1.14, J10.29
unnamed: J10.31, R5.1
unnamed: J10.33, R6.1
unnamed: J10.35, U4.12 (Dout)
unnamed: J10.37, SW3.3, SW3.4
unnamed: J10.38, U4.11 (Din)
unnamed: J10.40, U4.13 (CLK)
unnamed: IC1.10, J11.2
unnamed: J12.2, U4.1 (CH0)
unnamed: J13.2, U4.2 (CH1)
unnamed: J14.2, U4.3 (CH2)
unnamed: J15.2, U4.4 (CH3)
unnamed: JP2.2 (C), U2.17 (SA0/H_MOSI)
unnamed: C10.1, U2.9 (CAP)
VCC: C1.1, D2.1 (K), J7.1, SW1.1 (B)

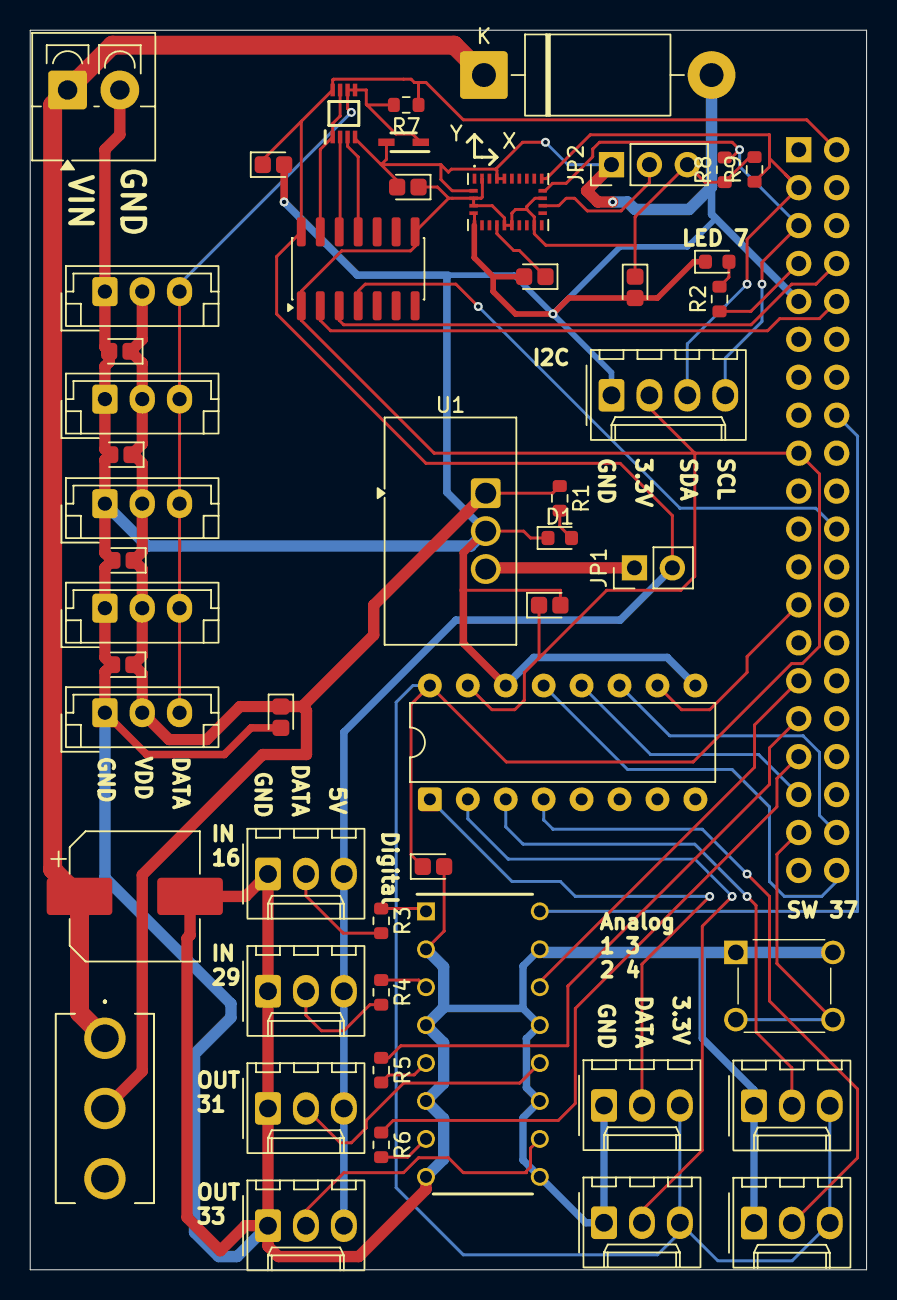
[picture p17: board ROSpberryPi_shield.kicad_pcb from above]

Board: 2 copper layers, 56.0 x 83.0 mm, 51 parts (1 on the bottom side), 41 nets.

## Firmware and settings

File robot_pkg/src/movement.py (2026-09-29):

#!/usr/bin/env python3
import os
import csv
import rclpy
from rclpy.node import Node
from std_msgs.msg import Bool, String, Float64MultiArray
from sensor_msgs.msg import JointState
from trajectory_msgs.msg import JointTrajectory, JointTrajectoryPoint
from control_msgs.action import FollowJointTrajectory
from builtin_interfaces.msg import Duration
from rclpy.action import ActionClient
from controller_manager_msgs.srv import SwitchController
from dynamixel_interfaces.srv import SetDataToDxl

class MoveRobot(Node):
    def __init__(self):
        super().__init__('move_robot_node')
        
        self.action_client = ActionClient(
            self, FollowJointTrajectory, '/joint_trajectory_controller/follow_joint_trajectory')
        
        self.servo_pub = self.create_publisher(
            String, '/FOBOT/servo', 10)
        
        self.movement_state_pub = self.create_publisher(
            String, '/FOBOT/movement_done', 10)
        
        self.create_subscription(
            String, '/FOBOT/state', self.state_cb, 10)
        
        self.create_subscription(
            String, 'FOBOT/movement_done', self.stop_signal_cb, 10)
        
        self.create_subscription(
            Bool, '/FOBOT/repeat_signal', self.repeat_cb, 10)
        
        self.switch_client = self.create_client(
            SwitchController, "/controller_manager/switch_controller")

        self.create_subscription(
            JointState, '/joint_states', self.joint_state_cb, 10)
            
        self.fobot_cmd_pub = self.create_publisher(
            Float64MultiArray, '/fobot_joint_controller/commands', 10)
            
        self.dxl_data_client = self.create_client(
            SetDataToDxl, '/dynamixel_hardware_interface/set_dxl_data')
        
        self.joint_names = [
            'joint_hombro', 'joint_hombro_codo', 'joint_codo',
            'joint_codo_muneca', 'joint_muneca', 'joint_herramienta'
        ]
        
        self.is_moving = False
        self.points_list = []
        self.current_mode = ""            
        self.latest_joint_state = None
        
    def joint_state_cb(self, msg):
        self.latest_joint_state = msg

    def preseed_fobot_controller(self):
        if self.latest_joint_state is None:
            self.get_logger().error('No /joint_states yet — refusing to switch without a safe pre-seed')
            return False
        try:
            positions = [self.latest_joint_state.position[self.latest_joint_state.name.index(j)]
                         for j in self.joint_names]
        except ValueError as e:
            self.get_logger().error(f'Joint missing from /joint_states: {e}')
            return False
        msg = Float64MultiArray(data=positions)
        for _ in range(3):
            self.fobot_cmd_pub.publish(msg)
        return True
        
    def publish_points(self, points_list):
        self.action_client.wait_for_server()
        
        goal_msg = FollowJointTrajectory.Goal()
        goal_msg.trajectory.joint_names = self.joint_names
        
        time_accum = 0.0
        time_interval = 5.0
        
        for row in points_list:
            float_row = [float(x) for x in row]
            time_accum += time_interval
            
            point = JointTrajectoryPoint()
            point.positions = float_row
            
            int_sec = int(time_accum)
            nanoseconds = int((time_accum - int_sec) * 1e9)
            point.time_from_start = Duration(sec=int_sec, nanosec=nanoseconds)
            
            goal_msg.trajectory.points.append(point)
            
        self.send_goal_future = self.action_client.send_goal_async(goal_msg)
        self.send_goal_future.add_done_callback(self.goal_response_callback)
        
    def goal_response_callback(self, future):
        goal_handle = future.result()
        if not goal_handle.accepted:
            self.get_logger().warning('Trayectoria rechazada')
            self.is_moving = False
            return
            
        self.get_logger().warning('Trayectoria aceptada')
        
        self.get_result_future = goal_handle.get_result_async()
        self.get_result_future.add_done_callback(self.get_result_callback)
        
    def get_result_callback(self, future):
        result = future.result().result
        
        if result.error_code == 0:
            self.get_logger().info(f'Trayectoria {self.current_mode} completada con éxito')
            
            msg = String()
            msg.data = self.current_mode
            
            if self.current_mode == "auto":
                if self.preseed_fobot_controller():
                    self.switch_controllers(
                        activate=["fobot_joint_controller"], 
                        deactivate=["joint_trajectory_controller"], 
                        end_cb=self.end_servo_cb
                    )
                else:
                    self.get_logger().error('Aborting switch to servo — pre-seed failed')
                    self.is_moving = False
            elif self.current_mode == "homing":
                self.movement_state_pub.publish(msg)
                self.is_moving = False
        else:
            self.get_logger().error(f"Error en la trayectoria. {result.error_code}")
            self.is_moving = False
        
    def switch_controllers(self, activate, deactivate, end_cb):
        # Comprobamos si el gestor de controladores de ROS 2 está vivo
        if not self.switch_client.wait_for_service(timeout_sec=2.0):
            self.get_logger().error('Servicio de cambio de controladores no disponible.')
            self.is_moving = False
            return
            
        # Preparamos la orden: Apagar trayectoria, Encender posición
        req = SwitchController.Request()
        req.activate_controllers = activate
        req.deactivate_controllers = deactivate
        req.strictness = SwitchController.Request.STRICT
        
        # Enviamos la orden de forma asincrona
        future = self.switch_client.call_async(req)
        future.add_done_callback(end_cb)
        
    def end_servo_cb(self, future):
        try:
            response = future.result()
            
            if response.ok:
                self.get_logger().info('El robot ya es controlado por Visión.')
                self.current_mode = "act_servo"
                msg = String()
                msg.data = self.current_mode
                self.movement_state_pub.publish(msg)
            else:
                self.get_logger().error('Error al cambiar al control por Visión.')
        except Exception as e:
            self.get_logger().error(f'Error al llamar al servicio: {e}')
        finally:
            self.is_moving = False
                
    def end_auto_cb(self, future):
        try:
            response = future.result()
            
            if response.ok:
                self.get_logger().info('El robot ya es controlado por Trayectorias.')
                self.current_mode = "deact_servo"
                msg = String()
                msg.data = self.current_mode
                self.movement_state_pub.publish(msg)
                
                if self.points_list:
                    self.is_moving = True
                    self.current_mode = "auto"
                    self.publish_points(self.points_list)
                else:
                    self.get_logger().warning("Señal ignorada")
                    self.is_moving = False
            else:
                self.get_logger().error("Error en el cambio de controlador")
                self.is_moving = False
        except Exception as e:
            self.get_logger().error(f'Error al llamar al servicio: {e}')
            self.is_moving = False
            
    def end_stop_cb(self, future):
        try:
            response = future.result()
            
            if response.ok:
                self.get_logger().info('El robot ya es controlado por Trayectorias.')
                self.current_mode = "stop"
                self.publish_points([[0.0, 0.0, 0.0, 0.0, 0.0, 0.0]])
                self.points_list = []
            else:
                self.get_logger().error("Error en el cambio de controlador")
        except Exception as e:
            self.get_logger().error(f'Error al llamar al servicio: {e}')
            self.is_moving = False
        
    def state_cb(self, msg):
        if msg.data and not self.is_moving:
        
            if 'HOMING' in msg.data:
                self.is_moving = True
                self.current_mode = "homing"
                self.publish_points([[0.0, 0.0, 0.0, 0.0, 0.0, 0.0]])
                
            elif 'AUTO' in msg.data:
                nombre_archivo = "/home/gromep/robot_ws/src/robot_pkg/src/trayectoria_dynamixel_rad.csv"

                if not os.path.exists(nombre_archivo):
                    self.get_logger().error(f"no se pudo abrir el archivo o la ruta está mal")
                    return
                    
                self.is_moving = True
                self.current_mode = "auto"
                self.points_list = []
                
                with open(nombre_archivo, "r") as f:
                    data = csv.reader(f)
                    for row in data:
                        if not row:
                            continue
                        self.points_list.append(row)
                    
                if self.points_list:
                    self.publish_points(self.points_list)
                else:
                    self.is_moving = False
                    
        elif msg.data and 'ERROR' in msg.data:
            self.is_moving = True
            self.current_mode = "error"
            
            if self.latest_joint_state == None:
                self.get_logger().error('No se puede bloquear')
                return
                
            try:
                current_positions = [self.latest_joint_state.position[self.latest_joint_state.name.index(j)] for j in self.joint_names]
            except ValueError as e:
                return
                
            self.publish_points([current_positions])
            
            msg_cmd = Float64MultiArray(data=current_positions)
            for _ in range(3):
                self.fobot_cmd_pub.publish(msg_cmd)
                
        elif msg.data and 'ESPERA' in msg.data:
            self.is_moving = False
                    
    def stop_signal_cb(self, msg):
        if 'stop' in msg.data:
            self.get_logger().info("Abortando secuencia y restaurando controladores...")
            self.is_moving = False
            self.switch_controllers(
                activate=["joint_trajectory_controller"], 
                deactivate=["fobot_joint_controller"], 
                end_cb=self.end_stop_cb # O un callback nuevo que simplemente libere el is_moving
            )
				
    def repeat_cb(self, msg):
        if msg.data and not self.is_moving:
            self.is_moving = True
            self.switch_controllers(
                activate=["joint_trajectory_controller"], 
                deactivate=["fobot_joint_controller"], 
                end_cb=self.end_auto_cb
            )
        
def main(args=None):
    rclpy.init(args=args)
    node = MoveRobot()
    try:
        rclpy.spin(node)
    except KeyboardInterrupt:
        pass
    finally:
        node.destroy_node()
        rclpy.shutdown()

if __name__ == '__main__':
    main()

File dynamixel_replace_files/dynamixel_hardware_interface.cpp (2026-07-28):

// Copyright 2024 ROBOTIS CO., LTD.
//
// Licensed under the Apache License, Version 2.0 (the "License");
// you may not use this file except in compliance with the License.
// You may obtain a copy of the License at
//
//     http://www.apache.org/licenses/LICENSE-2.0
//
// Unless required by applicable law or agreed to in writing, software
// distributed under the License is distributed on an "AS IS" BASIS,
// WITHOUT WARRANTIES OR CONDITIONS OF ANY KIND, either express or implied.
// See the License for the specific language governing permissions and
// limitations under the License.
//
// Authors: Hye-Jong KIM, Sungho Woo, Woojin Wie

#include "dynamixel_hardware_interface/dynamixel_hardware_interface.hpp"

#include <chrono>
#include <cmath>
#include <limits>
#include <memory>
#include <vector>
#include <string>
#include <map>
#include <unordered_map>
#include <iomanip>
#include <sstream>

#include "hardware_interface/types/hardware_interface_type_values.hpp"
#include "rclcpp/rclcpp.hpp"

namespace dynamixel_hardware_interface
{

DynamixelHardware::DynamixelHardware()
: rclcpp::Node("dynamixel_hardware_interface"),
  logger_(rclcpp::get_logger("dynamixel_hardware_interface"))
{
  dxl_status_ = DXL_OK;
  dxl_torque_status_ = TORQUE_ENABLED;
  err_timeout_ms_ = 500;
  is_read_in_error_ = false;
  is_write_in_error_ = false;
  read_error_duration_ = rclcpp::Duration(0, 0);
  write_error_duration_ = rclcpp::Duration(0, 0);
}

DynamixelHardware::~DynamixelHardware()
{
  stop();

  if (rclcpp::ok()) {
    RCLCPP_INFO(logger_, "Shutting down ROS2 node...");
  }
}

hardware_interface::CallbackReturn DynamixelHardware::on_init(
  const hardware_interface::HardwareInfo & info)
{
  if (hardware_interface::SystemInterface::on_init(info) !=
    hardware_interface::CallbackReturn::SUCCESS)
  {
    RCLCPP_ERROR_STREAM(logger_, "Failed to initialize DynamixelHardware");
    return hardware_interface::CallbackReturn::ERROR;
  }

  if (info_.hardware_parameters.find("number_of_joints") == info_.hardware_parameters.end()) {
    RCLCPP_ERROR_STREAM(
      logger_,
      "Required parameter 'number_of_joints' not found in hardware parameters");
    return hardware_interface::CallbackReturn::ERROR;
  }
  if (info_.hardware_parameters.find("number_of_transmissions") ==
    info_.hardware_parameters.end())
  {
    RCLCPP_ERROR_STREAM(
      logger_,
      "Required parameter 'number_of_transmissions' not found in hardware parameters");
    return hardware_interface::CallbackReturn::ERROR;
  }

  num_of_joints_ = static_cast<size_t>(stoi(info_.hardware_parameters["number_of_joints"]));
  num_of_transmissions_ =
    static_cast<size_t>(stoi(info_.hardware_parameters["number_of_transmissions"]));

  if (!SetMatrix()) {
    RCLCPP_ERROR_STREAM(logger_, "Failed to set transmission matrices");
    return hardware_interface::CallbackReturn::ERROR;
  }

  if (info_.hardware_parameters.find("port_name") == info_.hardware_parameters.end()) {
    RCLCPP_ERROR_STREAM(logger_, "Required parameter 'port_name' not found in hardware parameters");
    return hardware_interface::CallbackReturn::ERROR;
  }
  if (info_.hardware_parameters.find("baud_rate") == info_.hardware_parameters.end()) {
    RCLCPP_ERROR_STREAM(logger_, "Required parameter 'baud_rate' not found in hardware parameters");
    return hardware_interface::CallbackReturn::ERROR;
  }
  
  // Comprobamos que se ha especificado la versión del protocolo
  if (info_.hardware_parameters.find("protocol_version") == info_.hardware_parameters.end()) {
    RCLCPP_ERROR_STREAM(logger_, "Required parameter 'protocol_version' not found in hardware parameters");
    return hardware_interface::CallbackReturn::ERROR;
  } 

  port_name_ = info_.hardware_parameters["port_name"];
  baud_rate_ = info_.hardware_parameters["baud_rate"];
  // Guardamos en una variable el protocolo especificado
  protocol_version_ = std::stof(info_.hardware_parameters["protocol_version"]);
  if (info_.hardware_parameters.find("error_timeout_ms") != info_.hardware_parameters.end()) {
    try {
      err_timeout_ms_ = stod(info_.hardware_parameters["error_timeout_ms"]);
    } catch (const std::exception & e) {
      RCLCPP_ERROR(
        logger_, "Failed to parse error_timeout_ms parameter: %s, using default value",
        e.what());
    }
  } else {
    RCLCPP_INFO(logger_, "error_timeout_ms parameter not found, using default value of 500ms");
  }
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

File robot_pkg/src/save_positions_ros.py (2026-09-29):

#!/usr/bin/env python3
import os
import rclpy
from rclpy.node import Node
from sensor_msgs.msg import JointState
from std_msgs.msg import String
from std_srvs.srv import SetBool
from trajectory_msgs.msg import JointTrajectory, JointTrajectoryPoint
from builtin_interfaces.msg import Duration
from std_msgs.msg import Float64MultiArray
from time import sleep

class EnsenanzaCinestesicaNode(Node):
    def __init__(self):
        super().__init__('ensenanza_cinestesica_node')
        
        # --- CONFIGURACIÓN ---
        self.PIN_PULSADOR = 17
        self.ARCHIVO_CSV = "/home/gromep/robot_ws/src/robot_pkg/src/trayectoria_dynamixel_rad.csv"
        
        self.joint_names = [
            'joint_hombro', 'joint_hombro_codo', 'joint_codo',
            'joint_codo_muneca', 'joint_muneca', 'joint_herramienta'
        ]
        self.dxl_ids = [1, 2, 3, 4, 5, 6]
        
        self.latest_positions = {}
        self.captura_num = 1
        self.current_state = ""
        
        # --- SUSCRIPCIONES Y SERVICIOS ---
        self.create_subscription(
            JointState, '/joint_states', self.joint_states_cb, 10)
            
        self.create_subscription(
            String, '/FOBOT/state', self.state_cb, 10)
            
        self.create_subscription(
            String, '/FOBOT/interface', self.interface_cb, 10)
            
        self.torque_client = self.create_client(
            SetBool, '/dynamixel_hardware_interface/set_dxl_torque')
            
        self.traj_pub = self.create_publisher(
            JointTrajectory, '/joint_trajectory_controller/joint_trajectory', 10)
            
        self.cmd_pub = self.create_publisher(
            Float64MultiArray, '/fobot_joint_controller/commands', 10)
            
    def sincronizar_controladores(self):
        if len(self.latest_positions) < 6:
            return
            
        posiciones_actuales = [self.latest_positions[j] for j in self.joint_names]
            
        # 1. Sincronizamos el controlador de trayectorias (El principal)
        msg_traj = JointTrajectory()
        msg_traj.joint_names = self.joint_names
        
        point = JointTrajectoryPoint()
        point.positions = posiciones_actuales
        # Le damos un tiempo muy pequeño (0.1s) para que asimile la posición al instante
        point.time_from_start = Duration(sec=0, nanosec=100000000) 
        
        msg_traj.points.append(point)
        self.traj_pub.publish(msg_traj)
        
        # 2. Sincronizamos también el controlador de posición directa por seguridad
        msg_cmd = Float64MultiArray()
        msg_cmd.data = posiciones_actuales
        self.cmd_pub.publish(msg_cmd)
            
    def state_cb(self, msg):
        new_state = msg.data
        
        if new_state == 'MODO_MANUAL' and self.current_state != 'MODO_MANUAL':
            self.get_logger().info("APRENDIZAJE EMPEZADO")
            self.captura_num = 1
            if os.path.exists(self.ARCHIVO_CSV):
                os.remove(self.ARCHIVO_CSV)
            self.set_torque_all(False)
            
        elif new_state != 'MODO_MANUAL' and self.current_state == 'MODO_MANUAL':
            self.get_logger().info("APRENDIZAJE FINALIZADO")
            
            self.sincronizar_controladores()
            
            sleep(0.3)
            
            self.set_torque_all(True)
            
        self.current_state = new_state
        
    def interface_cb(self, msg):
        if self.current_state != 'MODO_MANUAL':
            return
            
        if msg.data == 'pulsacion_corta':
            self.guardar_punto()
            
    def joint_states_cb(self, msg):
        for i, name in enumerate(msg.name):
            self.latest_positions[name] = msg.position[i]

    def set_torque_all(self, enable):
        if not self.torque_client.wait_for_service(timeout_sec=2.0):
            self.get_logger().error("Servicio de torque no disponible.")
            return

        req = SetBool.Request()
        req.data = enable
        self.torque_client.call_async(req)
            
    def guardar_punto(self):
        self.get_logger().info("AAAAAAAAAAAAAAAAAAAAAAAAAAAAAAAAAAAAAAAAAAAAAA")
        if len(self.latest_positions) < 6:
            self.get_logger().warning("Faltan datos de articulaciones. Ignorando pulsación.")
            return
            
        try:
            # Extraemos y redondeamos las posiciones
            pos_rad = [
                round(self.latest_positions[j], 4) 
                for j in self.joint_names
            ]
            
            linea_csv = ",".join(map(str, pos_rad))
            
            # Abrimos en modo 'append' (añadir) para mayor seguridad ante cortes de luz
            with open(self.ARCHIVO_CSV, "a") as f:
                f.write(linea_csv + "\n")
                
            self.get_logger().info(f"Captura #{self.captura_num} guardada: [{linea_csv}]")
            self.captura_num += 1
            
        except KeyError as e:
            self.get_logger().error(f"Articulación no encontrada: {e}")
            
def main(args=None):
    rclpy.init(args=args)
    node = EnsenanzaCinestesicaNode()
    
    rclpy.spin(node)
    
    node.destroy_node()
    rclpy.shutdown()

if __name__ == '__main__':
    main()

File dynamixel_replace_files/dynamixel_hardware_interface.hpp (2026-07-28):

// Copyright 2024 ROBOTIS CO., LTD.
//
// Licensed under the Apache License, Version 2.0 (the "License");
// you may not use this file except in compliance with the License.
// You may obtain a copy of the License at
//
//     http://www.apache.org/licenses/LICENSE-2.0
//
// Unless required by applicable law or agreed to in writing, software
// distributed under the License is distributed on an "AS IS" BASIS,
// WITHOUT WARRANTIES OR CONDITIONS OF ANY KIND, either express or implied.
// See the License for the specific language governing permissions and
// limitations under the License.
//
// Authors: Hye-Jong KIM, Sungho Woo, Woojin Wie

#ifndef DYNAMIXEL_HARDWARE_INTERFACE__DYNAMIXEL_HARDWARE_INTERFACE_HPP_
#define DYNAMIXEL_HARDWARE_INTERFACE__DYNAMIXEL_HARDWARE_INTERFACE_HPP_

#include <memory>
#include <string>
#include <vector>
#include <map>
#include <unordered_map>
#include <functional>

#include "rclcpp/rclcpp.hpp"
#include "ament_index_cpp/get_package_share_directory.hpp"

#include "hardware_interface/handle.hpp"
#include "hardware_interface/hardware_info.hpp"
#include "hardware_interface/system_interface.hpp"
#include "hardware_interface/types/hardware_interface_return_values.hpp"
#include "hardware_interface/types/hardware_interface_type_values.hpp"

#include "dynamixel_hardware_interface/visibility_control.h"
#include "dynamixel_hardware_interface/dynamixel/dynamixel.hpp"

#include "dynamixel_interfaces/msg/dynamixel_state.hpp"
#include "dynamixel_interfaces/srv/get_data_from_dxl.hpp"
#include "dynamixel_interfaces/srv/set_data_to_dxl.hpp"
#include "dynamixel_interfaces/srv/reboot_dxl.hpp"

#include "realtime_tools/realtime_publisher.hpp"
#include "realtime_tools/realtime_buffer.hpp"

#include "std_srvs/srv/set_bool.hpp"


namespace dynamixel_hardware_interface
{
/**
 * @brief Constants for hardware state interface names.
 */
constexpr char HW_IF_HARDWARE_STATE[] = "hardware_state";
constexpr char HW_IF_TORQUE_ENABLE[] = "torque_enable";

/**
 * @brief Struct for handling variable types associated with Dynamixel components.
 */
typedef struct HandlerVarType_
{
  uint8_t id;                                /**< ID of the Dynamixel component. */
  uint8_t comm_id;                           /**< ID of the Dynamixel to be communicated. */
  std::string name;                          /**< Name of the component. */
  std::vector<std::string> interface_name_vec; /**< Vector of interface names. */
  std::vector<std::shared_ptr<double>> value_ptr_vec; /**< Vector interface values. */
} HandlerVarType;

/**
 * @brief Enum for Dynamixel status.
 */
typedef enum DxlStatus
{
  DXL_OK = 0,    /**< Normal status. */
  HW_ERROR = 1,  /**< Hardware error status. */
  COMM_ERROR = 2,/**< Communication error status. */
  REBOOTING = 3, /**< Rebooting status. */
} DxlStatus;

/**
 * @brief Enum for Dynamixel torque status.
 */
typedef enum DxlTorqueStatus
{
  TORQUE_ENABLED = 0,        /**< Torque is enabled. */
  TORQUE_DISABLED = 1,       /**< Torque is disabled. */
  REQUESTED_TO_ENABLE = 2,   /**< Torque enable is requested. */
  REQUESTED_TO_DISABLE = 3,  /**< Torque disable is requested. */
} DxlTorqueStatus;

/**
 * @class DynamixelHardware
 * @brief Class for interfacing with Dynamixel hardware using the ROS2 hardware interface.
 *
 * This class is responsible for initializing, reading, and writing to Dynamixel actuators.
 * It also handles errors, resets, and publishes state information using ROS2 services and topics.
 */
class DynamixelHardware : public
  hardware_interface::SystemInterface, rclcpp::Node
{
public:
  /**
   * @brief Constructor for DynamixelHardware.
   */
  DynamixelHardware();

  /**
   * @brief Destructor for DynamixelHardware.
   */
  ~DynamixelHardware();

  /**
   * @brief Initialization callback for hardware interface.
   * @param info Hardware information for the system.
   * @return Callback return indicating success or error.
   */
  DYNAMIXEL_HARDWARE_INTERFACE_PUBLIC
  hardware_interface::CallbackReturn on_init(const hardware_interface::HardwareInfo & info)
  override;

  /**
   * @brief Exports state interfaces for ROS2.
   * @return A vector of state interfaces.
   */
  DYNAMIXEL_HARDWARE_INTERFACE_PUBLIC
  std::vector<hardware_interface::StateInterface> export_state_interfaces() override;

  /**
   * @brief Exports command interfaces for ROS2.
   * @return A vector of command interfaces.
   */
  DYNAMIXEL_HARDWARE_INTERFACE_PUBLIC
  std::vector<hardware_interface::CommandInterface> export_command_interfaces() override;

  /**
   * @brief Callback for activating the hardware interface.
   * @param previous_state Previous lifecycle state.
   * @return Callback return indicating success or error.
   */
  DYNAMIXEL_HARDWARE_INTERFACE_PUBLIC
  hardware_interface::CallbackReturn on_activate(const rclcpp_lifecycle::State & previous_state)
  override;
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

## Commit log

2026-07-28 upload all files
    Uploaded all the files from the workspace
    [FOBOT.ros2_control.xacro, FOBOT.urdf.xacro, base_link.STL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]
2026-07-28 dynamixel files
    uploaded files that must replace some original files from dynamixel packages
    [dynamixel.hpp, dynamixel_hardware_interface.cpp, dynamixel_hardware_interface.hpp]
2026-09-29 FOBOT Model Uploaded
    [61808-2rs1.SLDASM, 61808-2rs1_01.SLDPRT, 61808-2rs1_02.SLDPRT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]
2026-09-29 PCB Files uploaded
    [PCB_Raspberry.kicad_pcb, PCB_Raspberry.kicad_sch, ROSpberryPi_shield.csv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]
2026-09-29 Some files modified
    Some files of the project have been modified
    [robot.urdf.xacro, trayectoria_dynamixel_rad.csv]
